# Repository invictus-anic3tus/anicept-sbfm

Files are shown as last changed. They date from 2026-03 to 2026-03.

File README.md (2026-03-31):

<div align="center">

  <h1>The Anicept SBFM</h1>

  Main Image

  <h3>By Anicetus</h3>

  <p display="inline">

  <a href="https://creativecommons.org/licenses/by-nc/4.0/">
    </a> <a href="https://hackclub.com/">
    
  </a>

  </p>

  <h4>The Self-Built Filament Monitor, a smart, DIY 3D printer tool that does more than your average filament detector.</h4>
</div>

<sub>This work is licensed under a
[Creative Commons Attribution-NonCommercial 4.0 International License](https://creativecommons.org/licenses/by-nc/4.0/).
</sub>

## About

Hi! I'm Anicetus, and I love 3D printers and making custom hardware. Recently, however, I had an issue where my 3D printer's extruder lost its grip on the filament, and so stopped extruding it in the middle of a print. This was, of course, not ideal, and caused a lot of wasted filament and time. To stop this from happening again, I introduce to you the SBFM! There are a lot of different filament sensors out there, ranging from the humble microswitch to costly, ultraprecise modules.

But this is one of the first to be precise, cheap, and _fully_ homemade. No custom PCBs. No plastic pieces that can't be 3D printed. This is the true maker's filament detector!

## Features

- A photoelectric sensor to measure how quickly the filament is moving
- A cheap but reliable ESP32C3 SuperMini microcontroller, which sends data over WiFi to the 3D printer host
- Bearings to ensure filament passes through smoothly
- ECAS04 connectors for routing filament
- A fully 3D printable case
- A compact form factor
- ... all this for ten bucks!

## Assembly + Usage

Assembly video coming soon! For now, please reference the CAD design to see how everything fits together :)

Wiring Diagram

Once it's assembled and filament passes through right, see the readme in the code folder to get it working software-wise!!

## Bill of Materials

|Part |Link |Cost  |Notes |
|---|---|---|---|
|ESP32C3 SuperMini |https://www.aliexpress.us/item/3256807292829704.html|$2.64 |These abound on AliExpress for very cheap |
|Photoelectric sensor|https://www.aliexpress.us/item/3256806022845294.html|$1.30 | |
|7x11x3 bearings |https://www.aliexpress.us/item/3256807442294068.html|$2.59 |3 needed |
|ECAS04 collet clips |https://www.aliexpress.us/item/3256806459368820.html|$1.89 |2 needed |
|Screws |https://www.aliexpress.us/item/2251832857570651.html|$1.85 |M2 self-tapping, 14mm long, pan head (3 needed)|
|Subtotal | |$10.27| |
|Tax | |$0.85 | |
|Total | |$11.12| |





## Contributing

<sub>aha somebody wishes to help me i see</sub>

If you'd like to request changes, suggest additions, or forcefully make me edit things, feel free to contact me via email (`me at anicetus dot dev`, preferred) or Discord (anic3tus).

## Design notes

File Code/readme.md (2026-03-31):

# How to use

Prerequisites:
- Arduino IDE
- The assembled module

*Remember not to plug in the ESP32's USB while it has 5V input!*

Please note that I am *not* a software guy. I used to be, but recently I seem to have lost my coding touch. And so, this code was made with not a little help from an AI; even still, I've looked over it in full and, from what I can remember about coding, it does check out. If anybody out there knows better, or would like to help me in coding a better version, I'm very open to collaboration! Email me at `me "at" anicetus "dot" dev`.

First, download the SBFM_Speed_Test folder and upload it into your Arduino IDE projects folder. Then open the app, select the project, and upload it to the ESP32 in the usual manner. It should immediately begin displaying the speed value measured by the photoelectric sensor in the console. To change the pin number that the ESP32 is reading from, simply change the variable in the file.

Then download the SBFM_Full_Code folder and open it in Arduino IDE, and input the blank network details. Ensure you have all the listed dependencies downloaded, then upload this file and unplug the esp32.

Next, on the Raspberry Pi Klipper host, run a `sudo apt update` and ensure mosquitto is installed (`sudo apt install -y mosquitto mosquitto-clients`). Enable + start it with `sudo systemctl enable mosquitto` and `sudo systemctl start mosquitto`. Then, create/edit `/etc/mosquitto/conf.d/local.conf` to have:

```
listener 1883
allow_anonymous true
```

Then restart: `sudo systemctl restart mosquitto`. Next, use `pip install paho-mqtt requests`. Make sure you can access a JSON with print_stats.state when running `curl http://localhost:7125/printer/objects/query?print_stats`.

Upload the filament_monitor.py file to the home/pi directory, and run `python3 filament_monitor.py` to manually test the code! Start a 3D print, and make sure the log lines update.
But we can't have it requiring a manual start every time. Create a new file at `/etc/systemd/system/filament_monitor.service` with the following:

```
[Unit]
Description=Filament Speed Monitor
After=network.target mosquitto.service

[Service]
ExecStart=/usr/bin/python3 /home/pi/filament_monitor.py
WorkingDirectory=/home/pi
Restart=always
RestartSec=5
User=pi

[Install]
WantedBy=multi-user.target
```

And enable the service with:

```
sudo systemctl daemon-reload
sudo systemctl enable filament_monitor
sudo systemctl start filament_monitor

# Watch logs live
journalctl -u filament_monitor -f
```

If you have issues with inaccuracy or mistaken failures, tune the values in the Pi's and the ESP32's code, such as TOLERANCE_FRACTION and STALL_TIMEOUT.

Once it seems to be working correctly (after manually causing the filament to get not extrude properly to test the failure detection), uncomment this line in the Pi's code: `r = requests.post(f"{MOONRAKER_URL}/printer/print/pause", timeout=3)`.

That should be it! Enjoy :)

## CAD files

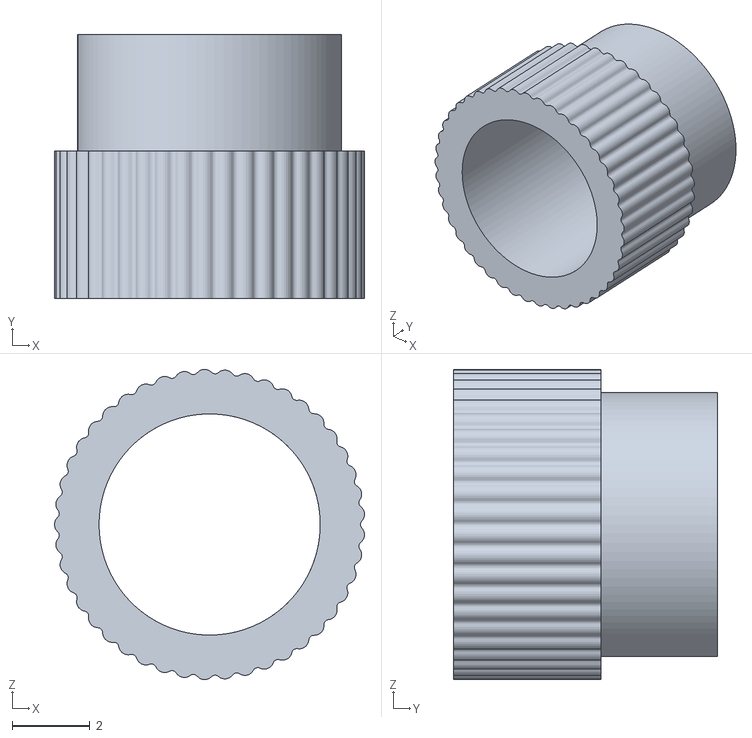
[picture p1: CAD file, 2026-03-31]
CAD/Main TPU Gear.stl
7.99 x 6.80 x 7.99

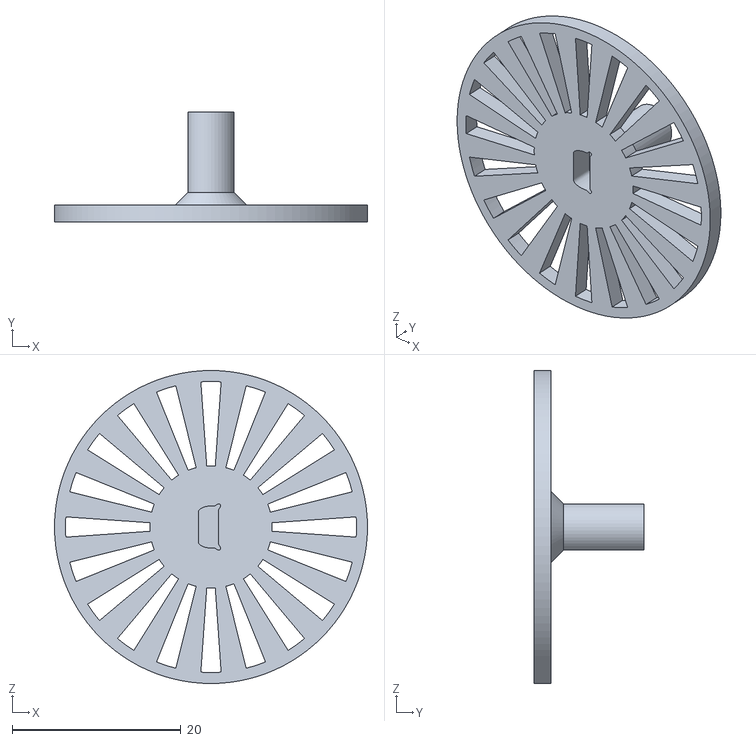
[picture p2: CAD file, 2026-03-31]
CAD/Main Gear.stl
37.1 x 13.0 x 37.1

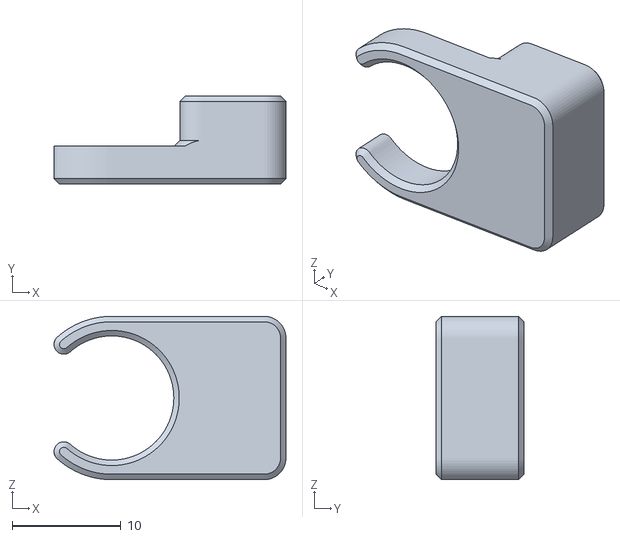
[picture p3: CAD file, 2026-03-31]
CAD/Tab.stl
21.3 x 8.10 x 15.0

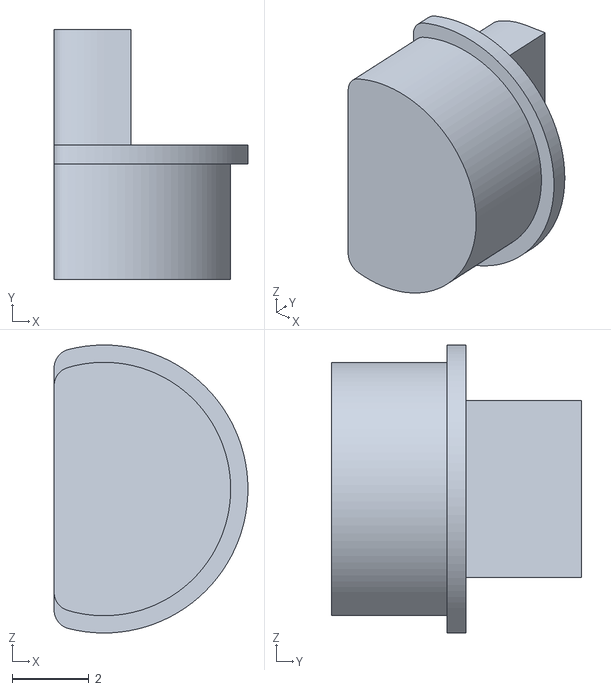
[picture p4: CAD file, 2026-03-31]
CAD/Gear Bottom Insert.stl
5.05 x 6.50 x 7.50

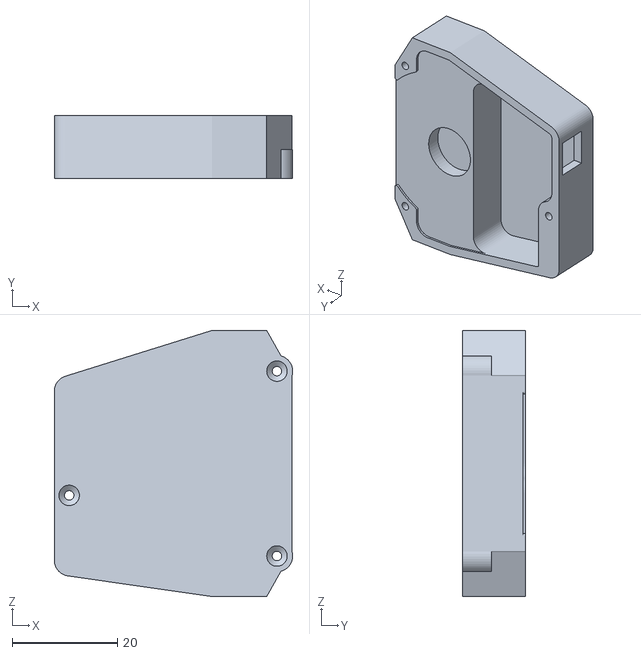
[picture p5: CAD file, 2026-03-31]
CAD/Bottom.stl
45.4 x 12.0 x 50.6

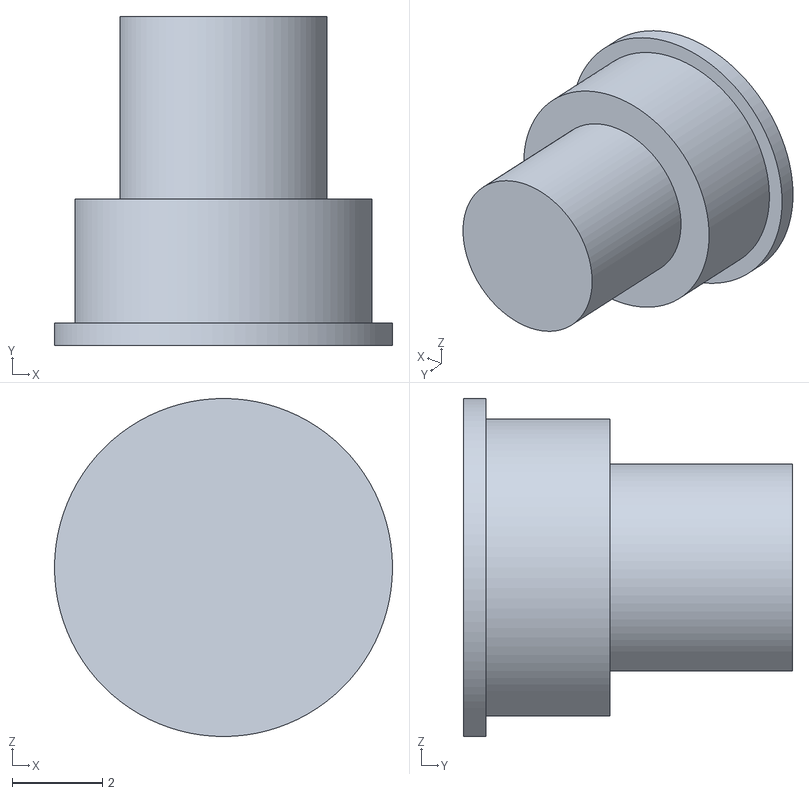
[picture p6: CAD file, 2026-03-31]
CAD/Tab Bearing Insert.stl
7.50 x 7.30 x 7.50

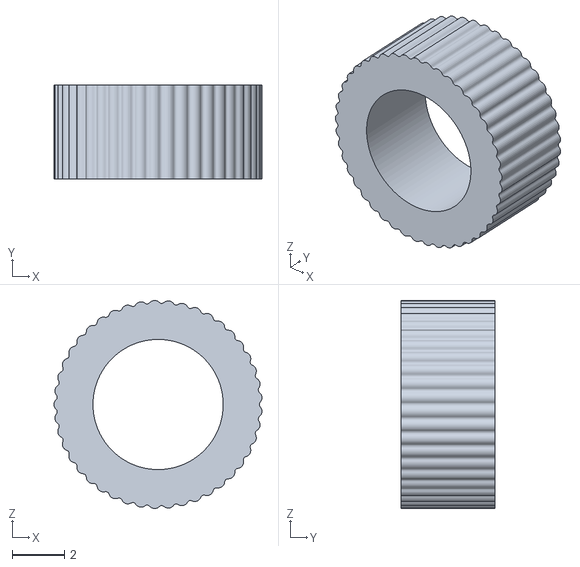
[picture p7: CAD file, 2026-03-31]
CAD/Tab TPU Gear.stl
7.99 x 3.60 x 7.99

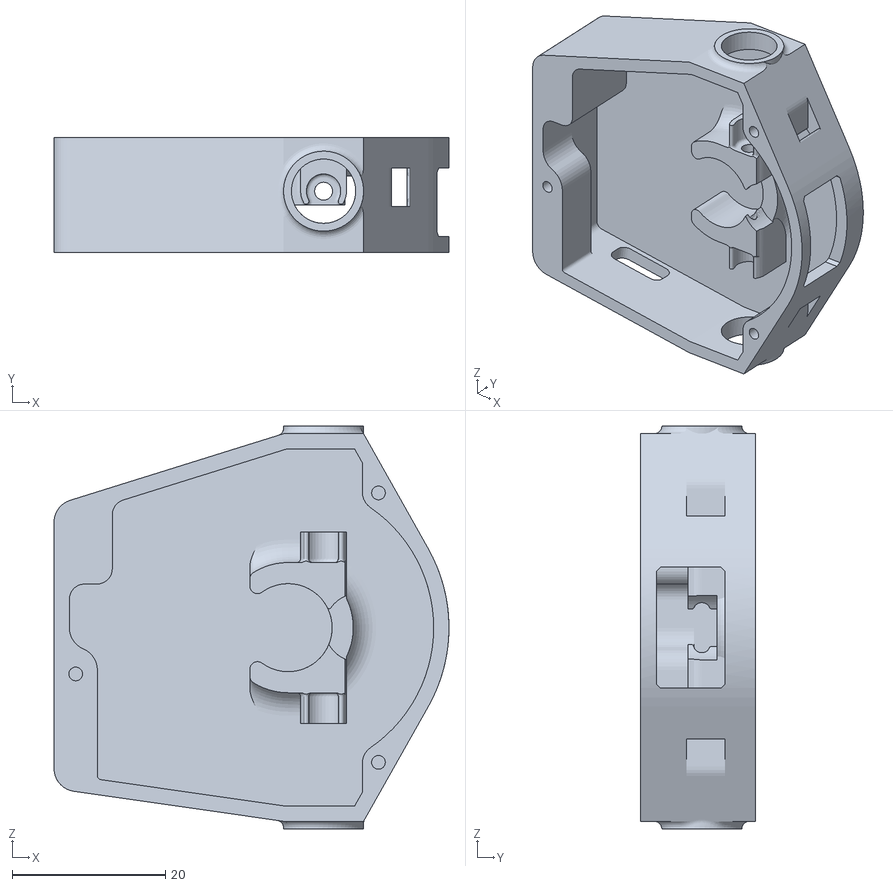
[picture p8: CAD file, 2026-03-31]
CAD/Top.stl
51.6 x 15.0 x 52.6

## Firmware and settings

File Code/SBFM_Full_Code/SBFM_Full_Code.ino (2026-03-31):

/*
 * LM393 Photoelectric Speed Sensor — ESP32-C3 SuperMini
 * Publishes speed data over MQTT to a Raspberry Pi.
 *
 * Wiring:
 *   LM393 D0 (signal) → GPIO 1
 *   LM393 VCC         → 3.3V
 *   LM393 GND         → GND
 *
 * Dependencies (install via Arduino Library Manager):
 *   - PubSubClient  by Nick O'Leary
 *   - ArduinoJson   by Benoit Blanchon
 */

#include <WiFi.h>
#include <PubSubClient.h>
#include <ArduinoJson.h>

// ── User config ───────────────────────────────────────────────
#define WIFI_SSID       "YOUR_WIFI_SSID"
#define WIFI_PASSWORD   "YOUR_WIFI_PASSWORD"
#define MQTT_BROKER     "192.168.1.XXX"   // IP of your Raspberry Pi
#define MQTT_PORT       1883
#define MQTT_TOPIC      "printer/filament/speed"
#define MQTT_CLIENT_ID  "esp32_filament_sensor"

// Optional MQTT auth — leave blank if not used
#define MQTT_USER       ""
#define MQTT_PASS       ""

// ── Pin & physical constant ───────────────────────────────────
#define SENSOR_PIN      1
const float MM_PER_CYCLE = 1.2565f;

// ── Timing ────────────────────────────────────────────────────
const int   AVG_WINDOW      = 5;      // rolling-average window (pulses)
const float STALL_TIMEOUT   = 500.0f; // ms — report zero speed after this
const int   PUBLISH_INTERVAL = 100;  // ms between MQTT publishes

// ── Globals ───────────────────────────────────────────────────
volatile unsigned long lastPulseUs   = 0;
volatile unsigned long intervalUs    = 0;
volatile bool          newPulse      = false;

float  intervalBuf[AVG_WINDOW];
int    bufIdx   = 0;
int    bufCount = 0;

WiFiClient   wifiClient;
PubSubClient mqtt(wifiClient);

// ── ISR ───────────────────────────────────────────────────────
void IRAM_ATTR onPulse() {
  unsigned long now = micros();
  if (lastPulseUs != 0) {
    intervalUs = now - lastPulseUs;
  }
  lastPulseUs = now;
  newPulse = true;
}

// ── Rolling average ───────────────────────────────────────────
void pushInterval(float us) {
  intervalBuf[bufIdx] = us;
  bufIdx = (bufIdx + 1) % AVG_WINDOW;
  if (bufCount < AVG_WINDOW) bufCount++;
}

float avgInterval() {
  if (bufCount == 0) return 0.0f;
  float sum = 0;
  for (int i = 0; i < bufCount; i++) sum += intervalBuf[i];
  return sum / bufCount;
}

// ── WiFi ──────────────────────────────────────────────────────
void connectWiFi() {
  Serial.print("Connecting to WiFi");
  WiFi.begin(WIFI_SSID, WIFI_PASSWORD);
  while (WiFi.status() != WL_CONNECTED) {
    delay(500);
    Serial.print(".");
  }
  Serial.printf("\nWiFi connected — IP: %s\n", WiFi.localIP().toString().c_str());
}

// ── MQTT ──────────────────────────────────────────────────────
void connectMQTT() {
  while (!mqtt.connected()) {
    Serial.print("Connecting to MQTT broker...");
    bool ok = (strlen(MQTT_USER) > 0)
      ? mqtt.connect(MQTT_CLIENT_ID, MQTT_USER, MQTT_PASS)
      : mqtt.connect(MQTT_CLIENT_ID);

    if (ok) {
      Serial.println(" connected.");
    } else {
      Serial.printf(" failed (rc=%d), retrying in 3s\n", mqtt.state());
      delay(3000);
    }
  }
}

// ── Publish ───────────────────────────────────────────────────
void publishSpeed(float speedMMs, bool stalled) {
  StaticJsonDocument<128> doc;
  doc["speed_mm_s"] = serialized(String(speedMMs, 3));
  doc["stalled"]    = stalled;
  doc["ts_ms"]      = millis();

  char buf[128];
  serializeJson(doc, buf);
  mqtt.publish(MQTT_TOPIC, buf);
}

// ── Setup ─────────────────────────────────────────────────────
void setup() {
  Serial.begin(115200);
  delay(400);

  pinMode(SENSOR_PIN, INPUT_PULLUP);
  attachInterrupt(digitalPinToInterrupt(SENSOR_PIN), onPulse, RISING);

  connectWiFi();
  mqtt.setServer(MQTT_BROKER, MQTT_PORT);
  connectMQTT();

  Serial.println("=== LM393 MQTT publisher running ===");
}

// ── Loop ──────────────────────────────────────────────────────
void loop() {
  if (!mqtt.connected()) connectMQTT();
  mqtt.loop();

  // Consume new pulse
  if (newPulse) {
    noInterrupts();
    unsigned long iv = intervalUs;
    newPulse = false;
    interrupts();
    pushInterval((float)iv);
  }

  // Publish on interval
  static unsigned long lastPublish = 0;
  if (millis() - lastPublish >= PUBLISH_INTERVAL) {
    lastPublish = millis();

    // Stall detection
    unsigned long lastMs;
    noInterrupts();
    lastMs = lastPulseUs / 1000;
    interrupts();

    bool stalled = (lastMs == 0) || ((millis() - lastMs) > (unsigned long)STALL_TIMEOUT);
    float speedMMs = 0.0f;

    if (!stalled && bufCount > 0) {
      float avg = avgInterval();
      if (avg > 0) {
        speedMMs = MM_PER_CYCLE / (avg / 1e6f);
      }
    }

    if (stalled) {
      bufCount = 0;
      speedMMs = 0.0f;
    }

    publishSpeed(speedMMs, stalled);

    Serial.printf("Published: %.3f mm/s%s\n",
      speedMMs, stalled ? " [STOPPED]" : "");
  }
}

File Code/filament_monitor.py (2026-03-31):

#!/usr/bin/env python3
"""
filament_monitor.py
────────────────────────────────────────────────────────────────
Subscribes to the ESP32's MQTT speed topic, polls Klipper's
Moonraker API for the expected filament feed rate, and raises
an alert when the measured speed deviates beyond the configured
tolerance — but ONLY while Klipper is actively printing and
extruding (not retracting, not idle, not in manual extrusion).

Dependencies:
    pip install paho-mqtt requests

Moonraker must be reachable on the local network (default: localhost).
"""

import time
import json
import logging
import threading
import requests
import paho.mqtt.client as mqtt

# ── User config ───────────────────────────────────────────────
MQTT_BROKER      = "localhost"          # mosquitto runs locally
MQTT_PORT        = 1883
MQTT_TOPIC       = "printer/filament/speed"
MQTT_USER        = ""                   # leave blank if no auth
MQTT_PASS        = ""

MOONRAKER_URL    = "http://localhost:7125"   # adjust if Moonraker is remote

# Tolerance: alert if |measured - expected| > TOLERANCE_FRACTION * expected
# e.g. 0.20 = allow ±20%
TOLERANCE_FRACTION = 0.20

# Minimum expected speed to bother checking (mm/s).
# Below this the extruder is basically idle / bridging; skip comparison.
MIN_CHECK_SPEED_MMS = 0.5

# How often to poll Moonraker for printer state (seconds)
POLL_INTERVAL = 0.25

# How many consecutive out-of-tolerance readings before alerting
ALERT_CONSECUTIVE = 3

# ── Logging ───────────────────────────────────────────────────
logging.basicConfig(
    level=logging.INFO,
    format="%(asctime)s  %(levelname)-8s  %(message)s",
    datefmt="%H:%M:%S",
)
log = logging.getLogger("filament_monitor")

# ── Shared state (written by MQTT thread, read by main loop) ──
_lock            = threading.Lock()
_measured_speed  = 0.0   # mm/s from sensor
_sensor_stalled  = True


# ══════════════════════════════════════════════════════════════
#  Moonraker helpers
# ══════════════════════════════════════════════════════════════

def _get(path: str, timeout: float = 2.0):
    """GET from Moonraker, return parsed JSON or None on failure."""
    try:
        r = requests.get(f"{MOONRAKER_URL}{path}", timeout=timeout)
        r.raise_for_status()
        return r.json()
    except Exception as exc:
        log.debug("Moonraker GET %s failed: %s", path, exc)
        return None


def get_printer_state() -> dict:
    """
    Returns a dict with keys:
        printing      bool   — a print job is active (not paused/idle)
        extruding     bool   — extruder is actively moving filament forward
        expected_mms  float  — filament feed rate in mm/s (volumetric-corrected to linear)
    """
    result = {
        "printing":     False,
        "extruding":    False,
        "expected_mms": 0.0,
    }

    # ── 1. Is a print job running (not paused, not standby)? ──
    job = _get("/printer/objects/query?print_stats")
    if not job:
        return result

    stats = job.get("result", {}).get("status", {}).get("print_stats", {})
    state = stats.get("state", "standby")   # idle | printing | paused | complete | error | standby
    if state != "printing":
        return result
    result["printing"] = True

    # ── 2. Query extruder motion objects ──────────────────────
    motion = _get(
        "/printer/objects/query"
        "?extruder"
        "&motion_report"
        "&gcode_move"
    )
    if not motion:
        return result

    status = motion.get("result", {}).get("status", {})

    extruder     = status.get("extruder", {})
    motion_rep   = status.get("motion_report", {})
    gcode_move   = status.get("gcode_move", {})

    # ── 3. Determine if extruder is pushing filament forward ──
    #
    # Klipper exposes `extruder.velocity` in mm/s (signed: + = extrude, - = retract).
    # If the key is absent, fall back to motion_report.live_velocity (scalar, unsigned)
    # cross-referenced with gcode_move.extrude_factor.
    #
    extruder_velocity = extruder.get("velocity", None)

    if extruder_velocity is not None:
        # Direct signed velocity — most reliable
        if extruder_velocity <= 0:
            # Retracting or idle — do not check
            return result
        result["extruding"]    = True
        result["expected_mms"] = float(extruder_velocity)
    else:
        # Fallback: use motion_report live velocity for the extruder axis.
        # live_extruder_velocity is available in some Klipper builds.
        live_e = motion_rep.get("live_extruder_velocity", None)
        if live_e is not None:
            if float(live_e) <= 0:
                return result
            result["extruding"]    = True
            result["expected_mms"] = float(live_e)
        else:
            # Last resort: if extruder pressure_advance position is advancing,
            # we can't reliably determine direction — skip.
            return result

    return result


# ══════════════════════════════════════════════════════════════
#  MQTT callbacks
# ══════════════════════════════════════════════════════════════

def on_connect(client, userdata, flags, rc):
    if rc == 0:
        log.info("Connected to MQTT broker.")
        client.subscribe(MQTT_TOPIC)
        log.info("Subscribed to %s", MQTT_TOPIC)
    else:
        log.error("MQTT connect failed (rc=%d)", rc)


def on_message(client, userdata, msg):
    global _measured_speed, _sensor_stalled
    try:
        data = json.loads(msg.payload)
        with _lock:
            _measured_speed = float(data.get("speed_mm_s", 0.0))
            _sensor_stalled = bool(data.get("stalled", True))
    except Exception as exc:
        log.warning("Bad MQTT payload: %s — %s", msg.payload, exc)


# ══════════════════════════════════════════════════════════════
#  Main monitoring loop
# ══════════════════════════════════════════════════════════════
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

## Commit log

2026-03-31 Upload CAD, software, and revamp readme
    [Anicept SBFM Bill of Materials.csv, Bottom.stl, Gear Bottom Insert.stl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]
2026-03-31 licensey licensey license
    cc by nc 🔥
2026-03-31 Update BOM
    Found a cheaper photoelectric sensor, bringing the total cost down to $10.21
    [Anicept SBFM Bill of Materials.csv]
